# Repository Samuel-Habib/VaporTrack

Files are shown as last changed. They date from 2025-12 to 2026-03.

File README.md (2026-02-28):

# VaporTrack: Autonomous Gas-Detection Rover






VaporTrack is an autonomous robotic rover powered by an **STM32F446RE (ARM Cortex-M4F @ 180 MHz)** running **FreeRTOS**. The rover characterizes spatial volatile organic compound (VOC) gas distributions in indoor environments, computes 2D spatial gradients ($\nabla G = [\partial G/\partial x, \partial G/\partial y]$) via weighted planar least-squares regression, and tracks plume sources while executing reactive obstacle avoidance using a 3-sensor ultrasonic array.

---

## 1. System Architecture

```text
                         ┌─────────────────────────┐
                         │   NUCLEO-F446RE (ARM)   │
                         │   180 MHz Cortex-M4F    │
                         │                         │
                         │   FreeRTOS (CMSIS-V2)   │
                         └────────────┬────────────┘
                                      │
             ┌────────────────────────┼────────────────────────┐
             │                        │                        │
        I2C1 (PB6/PB7)           TIM4 / GPIO             TIM1 PWM (PA8/PA10)
             │                        │                        │
      ┌──────┼──────┐           ┌─────┴─────┐            ┌─────┴─────┐
      │      │      │           │           │            │           │
    BME688 BNO055 OLED      HC-SR04 x3   Heartbeat     L298N H-Bridge
    (Gas)  (IMU)  (Diag)   (PC0 - PC5)     (PA5)             │
                                                       ┌─────┴─────┐
                                                       │           │
                                                   Left 4WD    Right 4WD
```

---

## 2. Hardware Specification

| Subsystem | Component | Bus / Interface | Operational Parameters | Role in System |
| :--- | :--- | :--- | :--- | :--- |
| **MCU** | STM32F446RET6 (Nucleo-64) | On-chip | 180 MHz, 512 KB Flash, 128 KB SRAM, FPU | Main controller, RTOS scheduler, spatial math |
| **RTOS** | FreeRTOS Kernel v10.3.1 | Software | CMSIS-RTOS v2 API, preemptive scheduling | Task timing, thread synchronization, IPC |
| **Gas / Environment** | Bosch BME688 | I2C1 (`0x77`, 100 kHz) | Forced mode, 320°C heater (150 ms dwell) | MOX gas resistance ($R_{gas}$), T, P, RH |
| **IMU / Heading** | Bosch BNO055 | I2C1 (`0x28`, 100 kHz) | NDOF fusion mode, internal sensor fusion | Absolute Euler yaw ($\theta$), dead-reckoning |
| **Diagnostics Display**| SSD1306 0.96" OLED | I2C1 (`0x3C`, 100 kHz) | 128x64 monochrome framebuffer | Real-time telemetry, state, gradient vector |
| **Distance Ranging** | 3x HC-SR04 Ultrasonic | GPIO + TIM4 (1 MHz) | Sequential 10 µs trigger, 1 µs timing resolution | Front, Left, and Right obstacle distance |
| **Motor Driver** | L298N Dual H-Bridge | TIM1 PWM + GPIO | 20 kHz PWM (ARR=8999), 2A max per channel | 4WD differential steering control |
| **Chassis & Motors** | YIKESHU 4WD Chassis | Mechanical | 4x DC gearmotors (1:48 gear ratio) | Differential mobility platform |
| **Power Regulation** | DFRobot DFR0831 Buck | DC-DC Step-Down | 7.4V input $\rightarrow$ 5.0V regulated (3A max) | Clean 5V logic & ultrasonic sensor supply |
| **Battery Source** | 2x 18650 Li-ion Cells | Series Pack (2S) | 7.4V nominal (8.4V peak), 2600 mAh | Primary rover energy source |

### Schematic
Schematic

### PCB Layout (Top)
PCB Layout

---

## 3. Electrical & Power Architecture

```text
   2S 18650 Li-ion Battery
      (7.4V - 8.4V)
           │
           ├───[ Main Switch ]───┬───────────────────────────────► L298N VMS (Motor Power)
           │                     │
           │                     ▼
           │           DFRobot Buck Converter (DFR0831)
           │                 (7.4V -> 5.0V Regulated)
           │                     │
           │                     ├───► HC-SR04 Ultrasonic Array (VCC = 5.0V)
           │                     │
           │                     ▼
           │           Nucleo-64 5V / E5V Rail
           │                     │
           │                     ▼
           │           On-Board LDO (5.0V -> 3.3V)
           │                     │
           │                     ├───► STM32F446RE MCU Core & Peripherals
           │                     ├───► Bosch BME688 Gas Sensor (VDD = 3.3V)
           │                     ├───► Bosch BNO055 9-DOF IMU (VDD = 3.3V)
           │                     └───► SSD1306 128x64 OLED Display (VDD = 3.3V)
           │
           └─────────────────────────────────────────────────────► Common Ground Bus (GND)
```

> [!NOTE]
> **Ground Isolation & Noise Mitigation:**
> The motor return current path through the L298N is tied to the central battery ground tab to prevent high-current switching noise from inducing ground bounce on the 3.3V analog and I2C lines. Echo pins PC1, PC3, and PC5 on the STM32F446RE are true **5V-tolerant (FT)** inputs, allowing direct interface with 5V HC-SR04 echo signals without resistive voltage dividers.

---

## 4. Hardware Pinout Map

| Signal Name | STM32 Pin | Function / Alternate Function | Electrical Characteristics | Notes |
| :--- | :--- | :--- | :--- | :--- |
| `I2C1_SCL` | **PB6** | `AF4` (I2C1) | Open-Drain, 4.7 kΩ pull-up | Shared I2C bus clock (BME688, BNO055, SSD1306) |
| `I2C1_SDA` | **PB7** | `AF4` (I2C1) | Open-Drain, 4.7 kΩ pull-up | Shared I2C bus data line |
| `ENA` (Left PWM) | **PA8** | `AF1` (`TIM1_CH1`) | Push-Pull, 20 kHz PWM | Left motor bank duty cycle (ARR=8999) |
| `ENB` (Right PWM)| **PA10**| `AF1` (`TIM1_CH3`) | Push-Pull, 20 kHz PWM | Right motor bank duty cycle (ARR=8999) |
| `IN1` | **PB10** | GPIO Output | Push-Pull, Low Speed | Left motor forward control |
| `IN2` | **PB4** | GPIO Output | Push-Pull, Low Speed | Left motor reverse control |
| `IN3` | **PB5** | GPIO Output | Push-Pull, Low Speed | Right motor forward control |
| `IN4` | **PB3** | GPIO Output | Push-Pull, Low Speed | Right motor reverse control |
| `USS_FRONT_TRIG` | **PC0** | GPIO Output | Push-Pull, High Speed | Front ultrasonic 10 µs trigger pulse |
| `USS_FRONT_ECHO` | **PC1** | GPIO Input (`FT` 5V-tolerant) | Floating / Internal Pull-down | Front echo pulse width measurement |
| `USS_LEFT_TRIG` | **PC2** | GPIO Output | Push-Pull, High Speed | Left ultrasonic 10 µs trigger pulse |
| `USS_LEFT_ECHO` | **PC3** | GPIO Input (`FT` 5V-tolerant) | Floating / Internal Pull-down | Left echo pulse width measurement |
| `USS_RIGHT_TRIG`| **PC4** | GPIO Output | Push-Pull, High Speed | Right ultrasonic 10 µs trigger pulse |
| `USS_RIGHT_ECHO`| **PC5** | GPIO Input (`FT` 5V-tolerant) | Floating / Internal Pull-down | Right echo pulse width measurement |
| `STATUS_LED` | **PA5** | `AF1` (`TIM2_CH1`) | Push-Pull PWM | Activity heartbeat LED (duty $\propto$ motor drive) |

---

## 5. Software Architecture & FreeRTOS Tasks

The application runs 6 prioritized, decoupled FreeRTOS tasks. Inter-task communication follows a **producer-consumer snapshot model**: sensors update a shared state struct protected by a FreeRTOS mutex (`g_sensor_mutex`), and consumer tasks copy local snapshots to eliminate torn reads without holding the bus.

In addition, access to the shared physical I2C1 bus (`hi2c1`) between `SensorTask` (reading BME688 and BNO055) and `DisplayTask` (flushing 1024-byte framebuffer to SSD1306) is serialized using a dedicated FreeRTOS mutex (`g_i2c_mutex`). To prevent bus starvation during BME688 gas sensor heating, the driver splits forced-mode triggering and data readout: `SensorTask` initiates the measurement, yields CPU execution via `osDelay(160)` while the heater stabilizes, and acquires `g_i2c_mutex` again only when measurement registers are ready to fetch.

```text
                   SensorTask       UltrasonicTask
                  (BME688/BNO055)     (HC-SR04 x3)
                        │                  │
                        ▼                  ▼
                ┌─────────────────────────────────┐
                │    Thread-Safe Sensor Snapshot  │  (sensors.c: g_sensors)
                └────────────────┬────────────────┘
                                 │
                     ┌───────────┴───────────┐
                     ▼                       ▼
                MappingTask           NavigationTask (State Machine)
             (2D Least-Squares)              │
                     │                       ▼
                     └──────────────►   MotorTask (L298N PWM/GPIO)
                                             │
                                             ▼
                                        DisplayTask (SSD1306 OLED)
```

### Task Scheduling Table

| Task Name | Period | Priority | Stack Size | Role & Responsibilities |
| :--- | :--- | :--- | :--- | :--- |
| **`MotorTask`** | 50 ms | `osPriorityHigh` (40) | 256 words (1 KB) | Translates navigation velocity commands to TIM1 PWM compare values and GPIO directions. |
| **`SensorTask`** | 250 ms | `osPriorityAboveNormal` (32) | 512 words (2 KB) | Triggers BME688 forced-mode gas read and polls BNO055 Euler heading in NDOF mode. |
| **`NavTask`** | 150 ms | `osPriorityAboveNormal` (32) | 512 words (2 KB) | Dead-reckoning position integration, state machine updates, and obstacle avoidance overrides. |
| **`USSTask`** | 100 ms | `osPriorityNormal` (24) | 256 words (1 KB) | Sequentially fires HC-SR04 triggers using TIM4 1 MHz counter with 1 ms inter-ping decay gaps. |
| **`MapTask`** | 500 ms | `osPriorityNormal` (24) | 512 words (2 KB) | Logs spatial samples and solves 2D planar weighted least-squares system for $\nabla G$. |
| **`DispTask`** | 500 ms | `osPriorityBelowNormal` (16) | 512 words (2 KB) | Formats telemetry strings and flushes 1024-byte framebuffer to SSD1306 OLED over I2C. |

---

## 6. Gas Mapping & Gradient Localization Theory

Standard plume-tracking approaches rely on instantaneous concentration thresholds (`if gas > threshold -> move forward`). In indoor environments, turbulent eddies and diffusion create local pockets of high concentration, causing naive rovers to stall or oscillate. VaporTrack uses a **two-pass planar spatial gradient estimation**:

### 1. Spatial Sample Acquisition
As the rover maneuvers, it logs discrete coordinate tuples:
$$S_i = (x_i, y_i, \theta_i, G_i)$$
Where $(x_i, y_i)$ is dead-reckoned position derived from heading $\theta_i$ and differential wheel displacement.

Because the BME688 metal-oxide semiconductor (MOX) sensor's raw resistance $R_{\text{gas}}$ drops when reducing VOC vapors interact with its heated sensing layer, the rover converts raw resistance into relative conductance $G_i$ ($\mu\text{S}$):
$$G_i = \frac{10^6}{R_{\text{gas}, i}}$$
This inversion guarantees that $G_i$ increases proportionally with gas plume concentration, allowing standard gradient ascent to naturally steer toward the gas source without sign inversion.

### 2. Weighted Planar Least-Squares Regression
In the localization phase, the rover models the local gas distribution in a neighborhood of radius R as a first-order planar surface centered at (x, y).

Setting up the normal equations:
```text
[ Sum(dx^2)    Sum(dx*dy) ] [ b ] = [ Sum(dx*G) ]
[ Sum(dx*dy)   Sum(dy^2)  ] [ c ] = [ Sum(dy*G) ]
```

Solving via Cramer's rule:
```text
D = Sum(dx^2)*Sum(dy^2) - Sum(dx*dy)^2

b = (Sum(dx*G)*Sum(dy^2) - Sum(dy*G)*Sum(dx*dy)) / D
c = (Sum(dx^2)*Sum(dy*G) - Sum(dx*dy)*Sum(dx*G)) / D
```

### 3. Gradient Ascent Steering
The estimated gradient vector gives the direction of steepest concentration change:
```text
Grad(G) = [b, c]
target_heading = atan2(c, b)
```

The rover computes heading error $e_\theta = \theta_{\text{target}} - \theta_{\text{current}}$ and applies differential steering proportional to $e_\theta$. When $\|\nabla G\|$ drops below the planar detection threshold and $G$ exceeds the plume peak threshold, the rover transitions to `NAV_STATE_SOURCE_FOUND`.

---

## 7. Navigation State Machine & Safety Overrides

```text
    ┌──────────────┐
    │  STATE_BOOT  │
    └──────┬───────┘
           │ Hardware peripherals ready
           ▼
    ┌──────────────┐
    │ INIT_SENSORS │
    └──────┬───────┘
           │ I2C devices acknowledged
           ▼
    ┌──────────────┐
    │ CALIBRATION  │◄────────┐ BNO055 NDOF cal dance
    └──────┬───────┘         │ (sys >= 1, gyro+mag >= 2)
           │ Calibration OK  │
           ▼                 │
    ┌──────────────┐         │
    │   MAPPING    ├─────────┘
    └──────┬───────┘
           │ Waypoint quota reached (>= 64 samples)
           ▼
    ┌──────────────┐
    │ LOCALIZATION │
    └──────┬───────┘
           │ Valid gradient computed (|grad| > threshold)
           ▼
    ┌──────────────┐
    │   TRACKING   ├───────────────────────────────┐
    └──────┬───────┘                               │
           │ Gas peak reached & grad flat          │
           ▼                                       ▼
    ┌──────────────┐                      ┌─────────────────┐
    │ SOURCE_FOUND │                      │ OBSTACLE_AVOID  │
    └──────────────┘                      └─────────────────┘
                                           ▲ (Preempts any state
                                           │  if d_front < 20 cm)
```

* **Obstacle Preemption:** If `dist_front_cm < 20.0 cm` or either side sensor detects an obstacle `< 15.0 cm`, the rover immediately halts forward movement and transitions into `NAV_STATE_OBSTACLE_AVOID`.
* **Escape Maneuver:** The rover pivots away from the closer side until clearance exceeds `40.0 cm`, then restores the previous state to resume gradient navigation.

---

## 8. Repository Layout

```text
VaporTrack/
├── Core/
│   ├── Inc/
│   │   ├── bme688.h           # Bosch BME688 MOX gas & environmental driver header
│   │   ├── bno055.h           # Bosch BNO055 9-DOF IMU & Euler orientation header
│   │   ├── hcsr04.h           # 3-channel HC-SR04 ultrasonic driver header
│   │   ├── ssd1306.h          # 128x64 OLED framebuffer driver & font header
│   │   ├── motor.h            # L298N differential drive & PWM interface header
│   │   ├── sensors.h          # Mutex-protected thread-safe sensor snapshot header
│   │   ├── mapping.h          # 2D spatial sample grid & least-squares gradient header
│   │   ├── navigation.h       # Autonomous finite state machine & obstacle avoidance header
│   │   ├── main.h             # Pin assignments, peripheral exports, and clock macros
│   │   └── FreeRTOSConfig.h   # FreeRTOS kernel configuration (32 KB heap, FPU enabled)
│   └── Src/
│       ├── bme688.c           # BME688 register access & datasheet compensation formulas
│       ├── bno055.c           # BNO055 NDOF mode setup & Euler heading acquisition
│       ├── hcsr04.c           # TIM4 microsecond pulse width timing & distance calculation
│       ├── ssd1306.c          # Framebuffer manipulation & 6x8 ASCII font renderer
│       ├── motor.c            # TIM1 PWM duty update & GPIO direction control
│       ├── sensors.c          # Global sensor snapshot & FreeRTOS mutex synchronization
│       ├── mapping.c          # Planar regression solver using Cramer's rule
│       ├── navigation.c       # Navigation state machine, steering laws & obstacle overrides
│       ├── main.c             # System clock setup, peripheral init & FreeRTOS task threads
│       └── stm32f4xx_hal_msp.c# Low-level MSP peripheral clock and GPIO initialization
├── Drivers/                   # STMicroelectronics STM32F4xx HAL & ARM CMSIS sources
├── Middlewares/               # FreeRTOS Kernel v10.3.1 sources and CMSIS-RTOS v2 wrapper
├── cmake/                     # CMake toolchain definitions for arm-none-eabi-gcc
├── vapor_track.ioc            # STM32CubeMX graphical configuration file
├── CMakeLists.txt             # Root CMake build configuration
├── commands.sh                # Portable build and test automation script
├── openocd.cfg                # OpenOCD target configuration for ST-Link V2/V2-1
└── LICENSE                    # MIT License
```

---

## 9. Building and Flashing

### Toolchain Prerequisites
* **CMake** $\ge$ 3.22
* **Ninja** or **Make**
* **GNU Arm Embedded Toolchain** (`arm-none-eabi-gcc` $\ge$ 10.3)
* **stlink-tools** or **OpenOCD**

### Compilation
```bash
# Clone repository
git clone https://github.com/Samuel-Habib/VaporTrack.git
cd VaporTrack

# Configure build directory
cmake -DCMAKE_TOOLCHAIN_FILE=cmake/gcc-arm-none-eabi.cmake -DCMAKE_BUILD_TYPE=Debug -B build

# Build ELF and generate binary
cmake --build build -j$(nproc 2>/dev/null || sysctl -n hw.logicalcpu)
```

### Flashing to STM32 Target
```bash
# Flash using CMake target (via st-flash)
cmake --build build --target flash

# Or flash binary directly with st-flash
st-flash --connect-under-reset --reset write build/vapor_track.bin 0x08000000

# Or using OpenOCD
openocd -f openocd.cfg -c "program build/vapor_track.elf verify reset exit"
```

---

## 10. Bench Calibration & Verification

1. **IMU Heading Calibration:** On power-up, the rover remains stationary for 3 seconds to let the gyroscope calibrate, then executes a slow rotational pivot. The OLED displays `CAL S:<sys> G:<gyro> M:<mag>`. Once `mag >= 2` and `gyro == 3`, calibration locks.
2. **Ultrasonic Ranging Verification:** Each channel can be probed on PC1, PC3, and PC5 with a logic analyzer. A 10 µs pulse on trigger generates an echo high pulse between 116 µs (2 cm) and 23.2 ms (400 cm).
3. **VOC Sensor Response Verification:** Exposing the BME688 to an isopropyl alcohol vapor source causes the MOX sensor resistance $R_{gas}$ to drop sharply from ~150 kΩ to < 10 kΩ. The OLED reflects real-time $R_{gas}$ drops and computes gradient vector arrows on the display.
4. **Motor Differential Trim:** If the chassis drifts slightly under equal PWM duty cycles due to motor gearbox variance, adjust `NAV_SPEED_CRUISE` offsets in `Core/Inc/navigation.h`.

---

## 11. License

This project is licensed under the MIT License - see the [LICENSE](LICENSE) file for details.

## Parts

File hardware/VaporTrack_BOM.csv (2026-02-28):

Item | Designator | Qty | Value | Package | Description | Suggested MPN | DigiKey Example
1 | C1, C2 | 2 | 10uF | 0805 | Capacitor 10uF 16V X7R 0805 | CL21A106KOQNNNE
2 | C3, C5, C6, C7, C8, C9 | 6 | 100nF | 0805 | Capacitor 0.1uF 50V X7R 0805 | CL21B104KBCNNNC
3 | C4 | 1 | 2.2uF | 0805 | Capacitor 2.2uF 16V X7R 0805 (VCAP) | CL21B225KOFNNNE
4 | R1 | 1 | 10k | 0805 | Resistor 10k 5% 0805 (BOOT0) | RC0805JR-0710KL
5 | R2, R3 | 2 | 4.7k | 0805 | Resistor 4.7k 5% 0805 (I2C Pullup) | RC0805JR-074K7L
6 | R4 | 1 | 330 | 0805 | Resistor 330 ohm 5% 0805 (LED) | RC0805JR-07330RL
7 | D1 | 1 | LED | 0805 | LED Green/Red 0805
8 | U1 | 1 | AMS1117-3.3 | SOT-223 | LDO Voltage Regulator 3.3V 1A
9 | U2 | 1 | STM32F446RET6 | LQFP-64 | MCU ARM Cortex-M4 180MHz 512KB Flash
10 | J1 | 1 | 2-pin Header | 2.54mm TH | Pin Header 1x02 2.54mm
11 | J2 | 1 | 5-pin Header | 2.54mm TH | SWD Debug Header 1x05 2.54mm
12 | J3, J4, J5, J6, J7, J8 | 6 | 4-pin Header | 2.54mm TH | Sensor Headers 1x04 2.54mm
13 | J9 | 1 | 7-pin Header | 2.54mm TH | Motor Driver Header 1x07 2.54mm

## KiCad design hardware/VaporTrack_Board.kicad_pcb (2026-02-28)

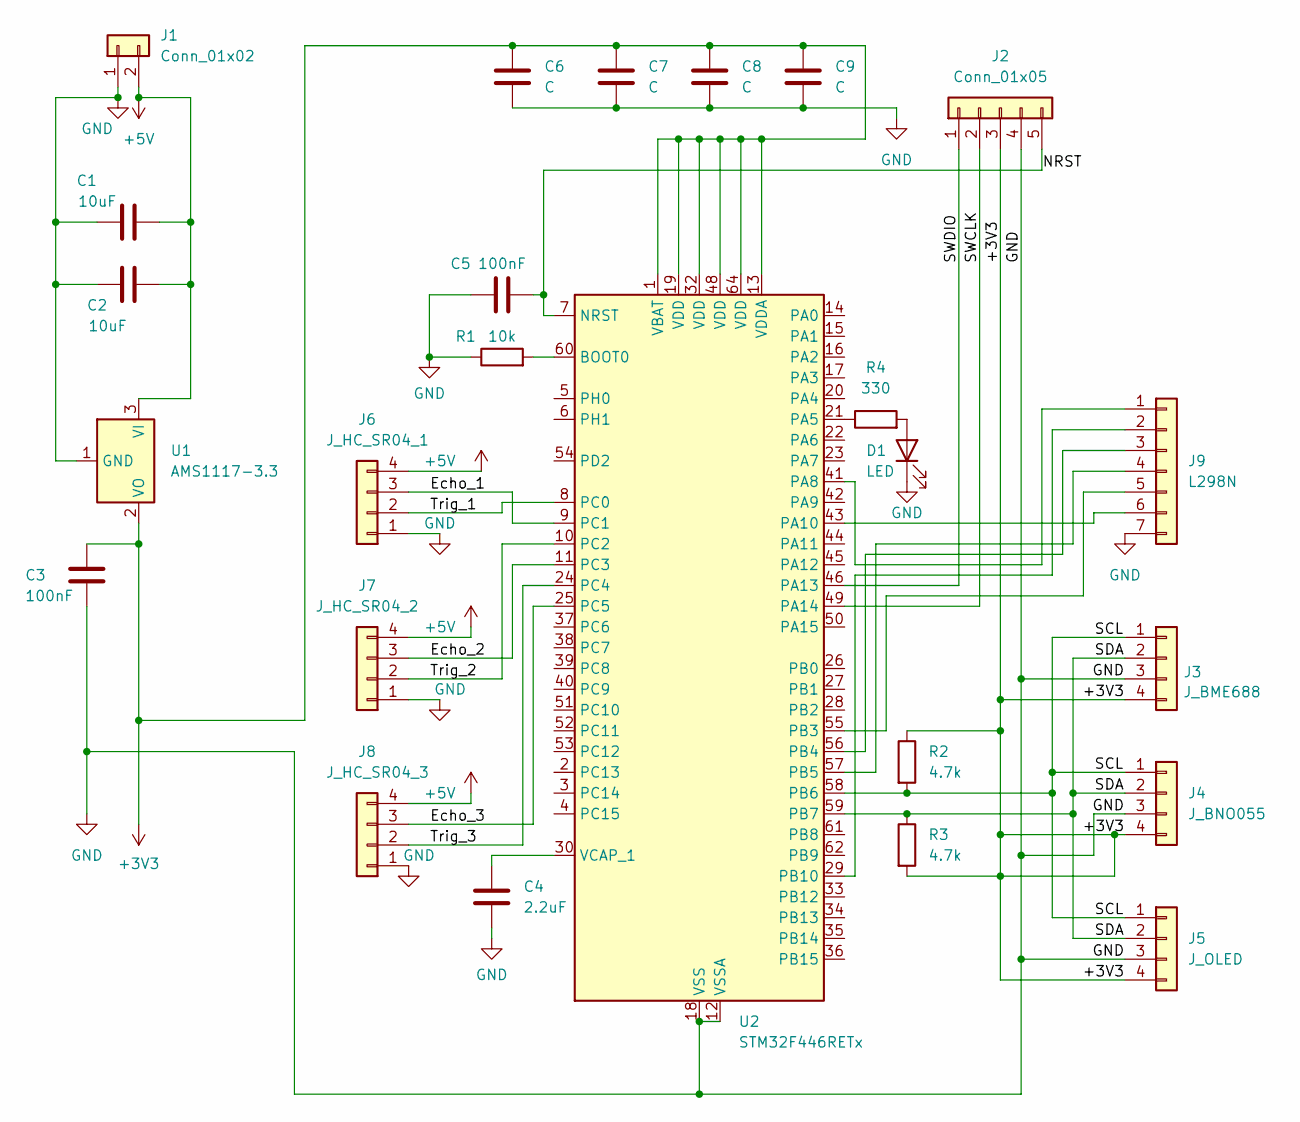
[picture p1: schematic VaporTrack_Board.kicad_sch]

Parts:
C1, C2: 10uF; C_0805_2012Metric
C3, C5: 100nF; C_0805_2012Metric
C4: 2.2uF; C_0805_2012Metric
C6, C7, C8, C9: C; C_0805_2012Metric
D1: LED; LED_0805_2012Metric
J1: Conn_01x02; PinHeader_1x02_P2.54mm_Vertical
J2: Conn_01x05; PinHeader_1x05_P2.54mm_Vertical
J3: J_BME688; PinHeader_1x04_P2.54mm_Vertical
J4: J_BNO055; PinHeader_1x04_P2.54mm_Vertical
J5: J_OLED; PinHeader_1x04_P2.54mm_Vertical
J6: J_HC_SR04_1; PinHeader_1x04_P2.54mm_Vertical
J7: J_HC_SR04_2; PinHeader_1x04_P2.54mm_Vertical
J8: J_HC_SR04_3; PinHeader_1x04_P2.54mm_Vertical
J9: L298N; PinHeader_1x07_P2.54mm_Vertical
R1: 10k; R_0805_2012Metric
R2, R3: 4.7k; R_0805_2012Metric
R4: 330; R_0805_2012Metric
U1: AMS1117-3.3; SOT-223-3_TabPin2
U2: STM32F446RETx; LQFP-64_10x10mm_P0.5mm

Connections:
+3V3: C3.1, C6.1, C7.2, C8.2, C9.1, J2.3, J3.4, J4.4, J5.4, R2.1, R3.2, U1.2 (VO), U2.1 (VBAT), U2.13 (VDDA), U2.19 (VDD), U2.32 (VDD), U2.48 (VDD), U2.64 (VDD)
+5V: C1.2, C2.2, J1.2, J6.4, J7.4, J8.4, U1.3 (VI)
/Echo_1: J6.3, U2.9 (PC1)
/Echo_2: J7.3, U2.11 (PC3)
/Echo_3: J8.3, U2.25 (PC5)
/NRST: C5.1, J2.5, U2.7 (NRST)
/SCL: J3.1, J4.1, J5.1, R2.2, U2.58 (PB6)
/SDA: J3.2, J4.2, J5.2, R3.1, U2.59 (PB7)
/SWCLK: J2.2, U2.49 (PA14)
/SWDIO: J2.1, U2.46 (PA13)
/Trig_1: J6.2, U2.8 (PC0)
/Trig_2: J7.2, U2.10 (PC2)
/Trig_3: J8.2, U2.24 (PC4)
GND: C1.1, C2.1, C3.2, C4.2, C5.2, C6.2, C7.1, C8.1, C9.2, D1.1 (K), J1.1, J2.4, J3.3, J4.3, J5.3, J6.1, J7.1, J8.1, J9.7, R1.1, U1.1 (GND), U2.12 (VSSA), U2.18 (VSS), U2.31 (VSS), U2.47 (VSS), U2.63 (VSS)
unnamed: D1.2 (A), R4.2
unnamed: J9.1, U2.41 (PA8)
unnamed: J9.2, U2.29 (PB10)
unnamed: J9.3, U2.56 (PB4)
unnamed: J9.4, U2.57 (PB5)
unnamed: J9.5, U2.55 (PB3)
unnamed: J9.6, U2.43 (PA10)
unnamed: R1.2, U2.60 (BOOT0)
unnamed: R4.1, U2.21 (PA5)
unnamed: C4.1, U2.30 (VCAP_1)

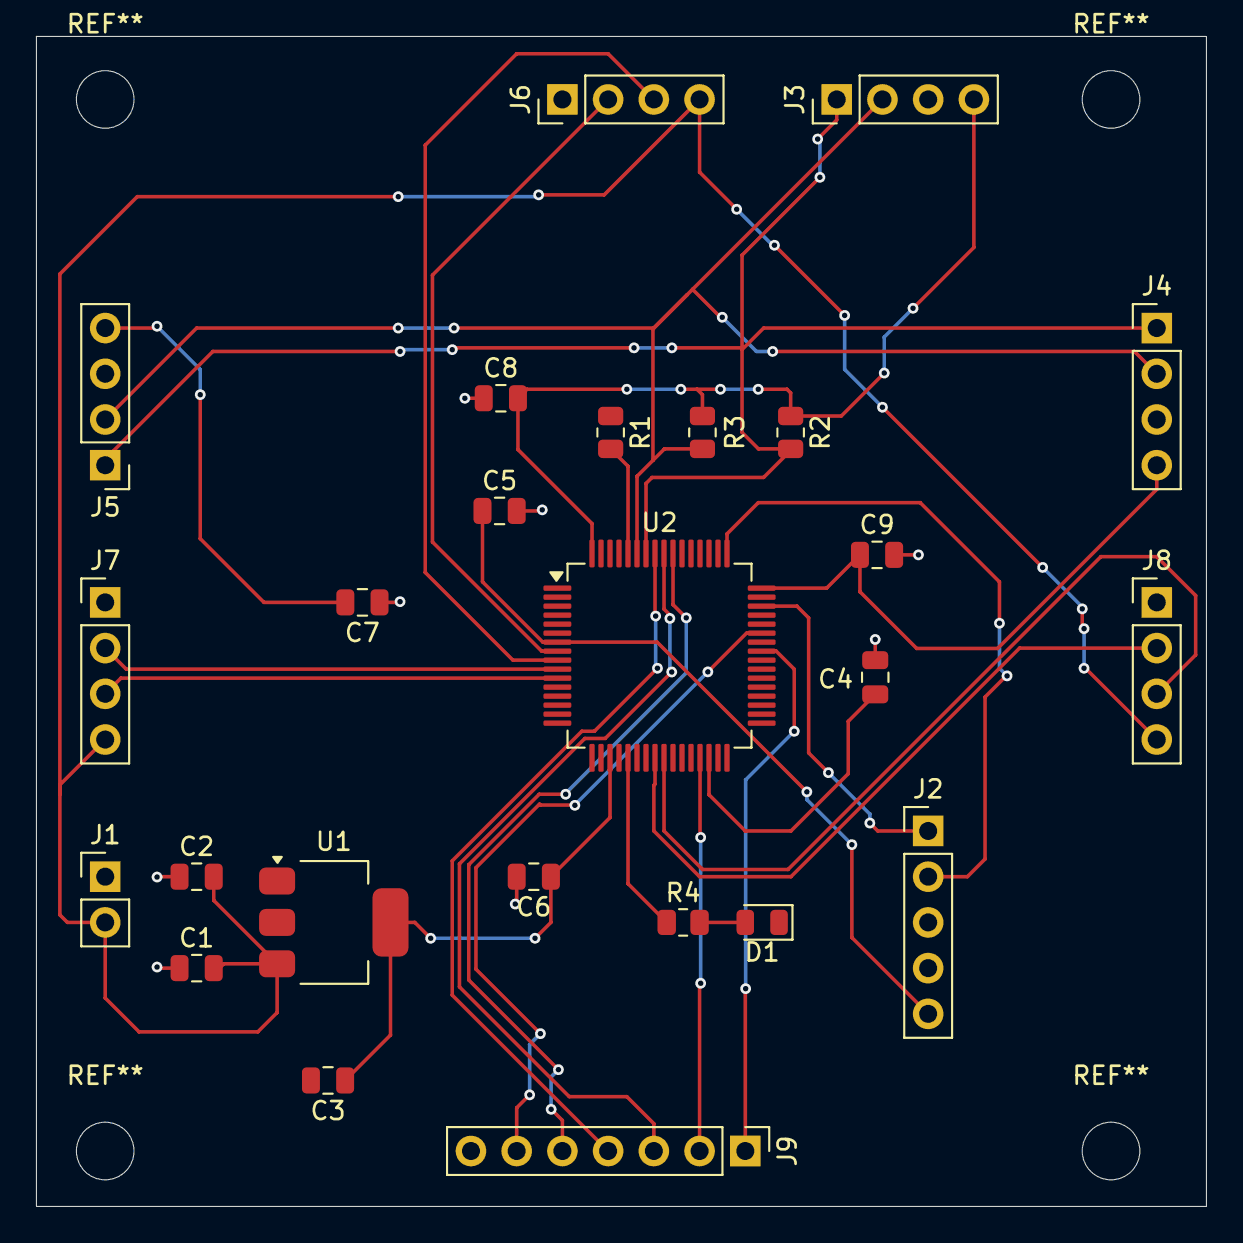
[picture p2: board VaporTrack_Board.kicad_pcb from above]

Board: 2 copper layers, 65.0 x 65.0 mm, 25 parts (0 on the bottom side), 24 nets.

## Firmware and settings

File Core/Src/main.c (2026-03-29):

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
/* Includes ------------------------------------------------------------------*/
#include "main.h"
#include "cmsis_os.h"

/* USER CODE BEGIN Includes */
#include "cmsis_os2.h"
#include "bme688.h"
#include "bno055.h"
#include "hcsr04.h"
#include "ssd1306.h"
#include "motor.h"
#include "sensors.h"
#include "mapping.h"
#include "navigation.h"

#include <stdio.h>
#include <string.h>
#include <math.h>
#include <stdlib.h>
/* USER CODE END Includes */

I2C_HandleTypeDef hi2c1;

TIM_HandleTypeDef htim1;
TIM_HandleTypeDef htim2;
TIM_HandleTypeDef htim4;

/* Definitions for SensorTask */
osThreadId_t SensorTaskHandle;
const osThreadAttr_t SensorTask_attributes = {
  .name = "SensorTask",
  .stack_size = 512 * 4,
  .priority = (osPriority_t) osPriorityAboveNormal,
};
/* Definitions for UltrasonicTask */
osThreadId_t UltrasonicTaskHandle;
const osThreadAttr_t UltrasonicTask_attributes = {
  .name = "USSTask",
  .stack_size = 256 * 4,
  .priority = (osPriority_t) osPriorityNormal,
};
/* Definitions for NavTask */
osThreadId_t NavTaskHandle;
const osThreadAttr_t NavTask_attributes = {
  .name = "NavTask",
  .stack_size = 512 * 4,
  .priority = (osPriority_t) osPriorityAboveNormal,
};
/* Definitions for MotorTask */
osThreadId_t MotorTaskHandle;
const osThreadAttr_t MotorTask_attributes = {
  .name = "MotorTask",
  .stack_size = 256 * 4,
  .priority = (osPriority_t) osPriorityHigh,
};
/* Definitions for MappingTask */
osThreadId_t MappingTaskHandle;
const osThreadAttr_t MappingTask_attributes = {
  .name = "MapTask",
  .stack_size = 512 * 4,
  .priority = (osPriority_t) osPriorityNormal,
};
/* Definitions for DisplayTask */
osThreadId_t DisplayTaskHandle;
const osThreadAttr_t DisplayTask_attributes = {
  .name = "DispTask",
  .stack_size = 512 * 4,
  .priority = (osPriority_t) osPriorityBelowNormal,
};
/* USER CODE BEGIN PV */
static bme688_dev_t   g_bme;
static bno055_dev_t   g_bno;
static hcsr04_dev_t   g_uss;
static ssd1306_dev_t  g_oled;
static motor_dev_t    g_motor;

static gas_map_t      g_map;
static nav_ctx_t      g_nav;

static volatile motor_cmd_t g_motor_cmd;
static SemaphoreHandle_t    g_motor_mutex;
static SemaphoreHandle_t    g_i2c_mutex;

static volatile bool g_bme_ok   = false;
static volatile bool g_bno_ok   = false;
static volatile bool g_oled_ok  = false;
/* USER CODE END PV */

void SystemClock_Config(void);
static void MX_GPIO_Init(void);
static void MX_I2C1_Init(void);
static void MX_TIM1_Init(void);
static void MX_TIM2_Init(void);
static void MX_TIM4_Init(void);
void SensorTask_Entry(void *argument);
void UltrasonicTask_Entry(void *argument);
void NavigationTask_Entry(void *argument);
void MotorTask_Entry(void *argument);
void MappingTask_Entry(void *argument);
void DisplayTask_Entry(void *argument);

/* USER CODE BEGIN PFP */
static inline void i2c_lock(void)
{
  if (g_i2c_mutex != NULL)
    xSemaphoreTake(g_i2c_mutex, portMAX_DELAY);
}

static inline void i2c_unlock(void)
{
  if (g_i2c_mutex != NULL)
    xSemaphoreGive(g_i2c_mutex);
}
/* USER CODE END PFP */

/**
  * @brief  The application entry point.
  * @retval int
  */
int main(void)
{
  /* MCU Configuration--------------------------------------------------------*/

  /* Reset of all peripherals, Initializes the Flash interface and the Systick. */
  HAL_Init();

  /* Configure the system clock */
  SystemClock_Config();

  /* Initialize all configured peripherals */
  MX_GPIO_Init();
  MX_I2C1_Init();
  MX_TIM1_Init();
  MX_TIM2_Init();
  MX_TIM4_Init();
  /* USER CODE BEGIN 2 */

  HAL_TIM_PWM_Start(&htim1, TIM_CHANNEL_1);
  HAL_TIM_PWM_Start(&htim1, TIM_CHANNEL_3);
  HAL_TIM_PWM_Start(&htim2, TIM_CHANNEL_1);

  sensors_init();
  map_init(&g_map);
  nav_init(&g_nav, &g_map);
  motor_init(&g_motor, &htim1);

  g_motor_mutex = xSemaphoreCreateMutex();
  g_i2c_mutex   = xSemaphoreCreateMutex();
  configASSERT(g_motor_mutex != NULL);
  configASSERT(g_i2c_mutex != NULL);

  /* USER CODE END 2 */

  /* Init scheduler */
  osKernelInitialize();

  /* Create the thread(s) */
  SensorTaskHandle = osThreadNew(SensorTask_Entry, NULL, &SensorTask_attributes);
  UltrasonicTaskHandle = osThreadNew(UltrasonicTask_Entry, NULL, &UltrasonicTask_attributes);
  NavTaskHandle = osThreadNew(NavigationTask_Entry, NULL, &NavTask_attributes);
  MotorTaskHandle = osThreadNew(MotorTask_Entry, NULL, &MotorTask_attributes);
  MappingTaskHandle = osThreadNew(MappingTask_Entry, NULL, &MappingTask_attributes);
  DisplayTaskHandle = osThreadNew(DisplayTask_Entry, NULL, &DisplayTask_attributes);

  /* Start scheduler */
  osKernelStart();

  /* We should never get here as control is now taken by the scheduler */
  /* Infinite loop */
  /* USER CODE BEGIN WHILE */
  while (1)
  {
    /* USER CODE END WHILE */

    /* USER CODE BEGIN 3 */
  }
  /* USER CODE END 3 */
}

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
/* USER CODE BEGIN Header_SensorTask_Entry */
/**
  * @brief  Function implementing the SensorTask thread.
  * @param  argument: Not used
  * @retval None
  */
/* USER CODE END Header_SensorTask_Entry */
void SensorTask_Entry(void *argument)
{
  /* USER CODE BEGIN 5 */
  (void)argument;

  i2c_lock();
  if (bme688_init(&g_bme, &hi2c1) == BME688_OK)
    g_bme_ok = true;

  if (bno055_init(&g_bno, &hi2c1) == BNO055_OK)
    g_bno_ok = true;
  i2c_unlock();

  for (;;)
  {
    uint32_t now = HAL_GetTick();

    if (g_bme_ok)
    {
      bme688_data_t env;
      i2c_lock();
      bme688_status_t trig_res = bme688_trigger_forced(&g_bme);
      i2c_unlock();

      if (trig_res == BME688_OK)
      {
        /* Yield to RTOS while sensor heater stabilizes (150ms dwell).
         * I2C bus is released so DisplayTask can flush without contention. */
        osDelay(160);

        i2c_lock();
        bme688_status_t read_res = bme688_read_data(&g_bme, &env);
        i2c_unlock();

        if (read_res == BME688_OK)
        {
          sensors_lock();
          g_sensors.gas_resistance   = env.gas_resistance;
          g_sensors.temperature      = env.temperature;
          g_sensors.humidity         = env.humidity;
          g_sensors.pressure         = env.pressure;
          g_sensors.gas_valid        = env.gas_valid;
          g_sensors.gas_heater_stable = env.heat_stab;
          g_sensors.gas_timestamp_ms  = now;
          sensors_unlock();
        }
      }
    }

    if (g_bno_ok)
    {
      bno055_euler_t euler;
      bno055_cal_status_t cal;
      i2c_lock();
      bno055_status_t euler_res = bno055_read_euler(&g_bno, &euler);
      if (euler_res == BNO055_OK)
      {
        bno055_get_calibration(&g_bno, &cal);
      }
      i2c_unlock();

      if (euler_res == BNO055_OK)
      {
        sensors_lock();
        g_sensors.heading_deg    = euler.heading;
        g_sensors.roll_deg       = euler.roll;
        g_sensors.pitch_deg      = euler.pitch;
        g_sensors.cal_sys        = cal.sys;
        g_sensors.cal_gyro       = cal.gyro;
        g_sensors.cal_accel      = cal.accel;
        g_sensors.cal_mag        = cal.mag;
        g_sensors.imu_calibrated = bno055_is_calibrated(&cal);
        g_sensors.imu_timestamp_ms = now;
        sensors_unlock();
      }
    }

    osDelay(100);
  }
  /* USER CODE END 5 */
}

/* USER CODE BEGIN Header_UltrasonicTask_Entry */
/**
* @brief Function implementing the UltrasonicTask thread.
* @param argument: Not used
* @retval None
*/
/* USER CODE END Header_UltrasonicTask_Entry */
void UltrasonicTask_Entry(void *argument)
{
  /* USER CODE BEGIN UltrasonicTask_Entry */
  (void)argument;

  hcsr04_init(&g_uss, &htim4);

  g_uss.hw[HCSR04_FRONT].trig_port = USS_FRONT_TRIG_Port;
  g_uss.hw[HCSR04_FRONT].trig_pin  = USS_FRONT_TRIG_Pin;
  g_uss.hw[HCSR04_FRONT].echo_port = USS_FRONT_ECHO_Port;
  g_uss.hw[HCSR04_FRONT].echo_pin  = USS_FRONT_ECHO_Pin;

  g_uss.hw[HCSR04_LEFT].trig_port  = USS_LEFT_TRIG_Port;
  g_uss.hw[HCSR04_LEFT].trig_pin   = USS_LEFT_TRIG_Pin;
  g_uss.hw[HCSR04_LEFT].echo_port  = USS_LEFT_ECHO_Port;
  g_uss.hw[HCSR04_LEFT].echo_pin   = USS_LEFT_ECHO_Pin;

  g_uss.hw[HCSR04_RIGHT].trig_port = USS_RIGHT_TRIG_Port;
  g_uss.hw[HCSR04_RIGHT].trig_pin  = USS_RIGHT_TRIG_Pin;
  g_uss.hw[HCSR04_RIGHT].echo_port = USS_RIGHT_ECHO_Port;
  g_uss.hw[HCSR04_RIGHT].echo_pin  = USS_RIGHT_ECHO_Pin;

  for (;;)
  {
    hcsr04_measure_all(&g_uss);

    sensors_lock();
    g_sensors.dist_front_cm = g_uss.distance_cm[HCSR04_FRONT];
    g_sensors.dist_left_cm  = g_uss.distance_cm[HCSR04_LEFT];
    g_sensors.dist_right_cm = g_uss.distance_cm[HCSR04_RIGHT];
    g_sensors.uss_timestamp_ms = HAL_GetTick();
    sensors_unlock();

    osDelay(100);
  }
  /* USER CODE END UltrasonicTask_Entry */
}

/* USER CODE BEGIN Header_NavigationTask_Entry */
/**
* @brief Function implementing the NavTask thread.
* @param argument: Not used
* @retval None
*/
/* USER CODE END Header_NavigationTask_Entry */
void NavigationTask_Entry(void *argument)
{
  /* USER CODE BEGIN NavigationTask_Entry */
  (void)argument;

  osDelay(500);

  for (;;)
  {
    sensor_data_t snap;
    sensors_copy(&snap);

    nav_sensor_input_t input;
    /* Convert MOX gas resistance (ohms) to relative conductance (uS):
     * As VOC concentration increases, MOX resistance drops, so conductance
     * (1/R) increases proportionally with gas plume intensity. */
    if (snap.gas_resistance > 100.0f) {
      input.gas = 1000000.0f / snap.gas_resistance;
    } else {
      input.gas = 0.0f;
    }
    input.temperature   = snap.temperature;
    input.humidity      = snap.humidity;
    input.pressure      = snap.pressure;
    input.gas_valid     = snap.gas_valid;
    input.heading_deg   = snap.heading_deg;
    input.heading_valid = snap.imu_calibrated;
    input.dist_front_cm = snap.dist_front_cm;
    input.dist_left_cm  = snap.dist_left_cm;
    input.dist_right_cm = snap.dist_right_cm;
    input.pos_x         = g_nav.pos_x;
    input.pos_y         = g_nav.pos_y;

    uint32_t now = HAL_GetTick();
    motor_cmd_t cmd = nav_update(&g_nav, &input, now);

    xSemaphoreTake(g_motor_mutex, portMAX_DELAY);
    g_motor_cmd = cmd;
    xSemaphoreGive(g_motor_mutex);

    sensors_lock();
    g_sensors.pos_x = g_nav.pos_x;
    g_sensors.pos_y = g_nav.pos_y;
    sensors_unlock();

    osDelay(150);
  }
  /* USER CODE END NavigationTask_Entry */
}

/* USER CODE BEGIN Header_MotorTask_Entry */
/**
* @brief Function implementing the MotorTask thread.
* @param argument: Not used
* @retval None
*/
/* USER CODE END Header_MotorTask_Entry */
void MotorTask_Entry(void *argument)
{
  /* USER CODE BEGIN MotorTask_Entry */
  (void)argument;

  for (;;)
  {
    motor_cmd_t cmd;
    xSemaphoreTake(g_motor_mutex, portMAX_DELAY);
    cmd = g_motor_cmd;
    xSemaphoreGive(g_motor_mutex);

    motor_set(&g_motor, cmd.left, cmd.right);

    uint16_t activity = (uint16_t)(abs(cmd.left) + abs(cmd.right)) / 2;
    if (activity < 500) activity = 500;
    __HAL_TIM_SET_COMPARE(&htim2, TIM_CHANNEL_1, activity);

    osDelay(50);
  }
  /* USER CODE END MotorTask_Entry */
}

/* USER CODE BEGIN Header_MappingTask_Entry */
/**
* @brief Function implementing the MappingTask thread.
* @param argument: Not used
* @retval None
*/
/* USER CODE END Header_MappingTask_Entry */
void MappingTask_Entry(void *argument)
{
  /* USER CODE BEGIN MappingTask_Entry */
  (void)argument;

  for (;;)
  {
    sensor_data_t snap;
    sensors_copy(&snap);

    if (g_map.count > 3)
    {
      g_map.gradient = map_estimate_gradient(&g_map, snap.pos_x, snap.pos_y, 1.5f);
    }

    osDelay(500);
  }
  /* USER CODE END MappingTask_Entry */
}

/* USER CODE BEGIN Header_DisplayTask_Entry */
/**
* @brief Function implementing the DisplayTask thread.
* @param argument: Not used
* @retval None
*/
/* USER CODE END Header_DisplayTask_Entry */
void DisplayTask_Entry(void *argument)
{
  /* USER CODE BEGIN DisplayTask_Entry */
  (void)argument;

  i2c_lock();
  if (ssd1306_init(&g_oled, &hi2c1) == SSD1306_OK)
    g_oled_ok = true;
  i2c_unlock();

  char line[22];

  for (;;)
  {
    if (!g_oled_ok)
    {
      osDelay(2000);
      continue;
    }

    sensor_data_t snap;
    sensors_copy(&snap);

    ssd1306_clear(&g_oled);

    snprintf(line, sizeof(line), "%-10s %3d%%",
             nav_state_name(g_nav.state),
             (int)(snap.cal_sys * 33));
    ssd1306_puts(&g_oled, 0, 0, line);

    snprintf(line, sizeof(line), "GAS:%-6d %4.1fC",
             (int)snap.gas_resistance, (double)snap.temperature);
    ssd1306_puts(&g_oled, 0, 8, line);

    snprintf(line, sizeof(line), "H:%4.1f%% P:%5.0f",
             (double)snap.humidity, (double)(snap.pressure / 100.0f));
    ssd1306_puts(&g_oled, 0, 16, line);

    snprintf(line, sizeof(line), "F:%3d L:%3d R:%3d",
             (int)snap.dist_front_cm,
             (int)snap.dist_left_cm,
             (int)snap.dist_right_cm);
    ssd1306_puts(&g_oled, 0, 24, line);

    snprintf(line, sizeof(line), "X:%5.2f Y:%5.2f",
             (double)snap.pos_x, (double)snap.pos_y);
    ssd1306_puts(&g_oled, 0, 32, line);

    snprintf(line, sizeof(line), "HDG:%3d", (int)snap.heading_deg);
    ssd1306_puts(&g_oled, 0, 40, line);

    if (g_map.gradient.valid)
    {
      snprintf(line, sizeof(line), "dG:%+.0f @%3d",
               (double)g_map.gradient.magnitude,
               (int)g_map.gradient.direction_deg);
      ssd1306_puts(&g_oled, 0, 48, line);
    }

    snprintf(line, sizeof(line), "MAP:%d/%d",
             g_map.count, MAP_MAX_SAMPLES);
    ssd1306_puts(&g_oled, 0, 56, line);

    i2c_lock();
    ssd1306_flush(&g_oled);
    i2c_unlock();

    osDelay(500);
  }
  /* USER CODE END DisplayTask_Entry */
}

/**
  * @brief  Period elapsed callback in non blocking mode
  * @note   This function is called  when TIM6 interrupt took place, inside
  * HAL_TIM_IRQHandler(). It makes a direct call to HAL_IncTick() to increment
  * a global variable "uwTick" used as application time base.
  * @param  htim : TIM handle
  * @retval None
  */
void HAL_TIM_PeriodElapsedCallback(TIM_HandleTypeDef *htim)
{
  if (htim->Instance == TIM6) {
    HAL_IncTick();
  }
}

/**
  * @brief  This function is executed in case of error occurrence.
  * @retval None
  */
void Error_Handler(void)
{
  /* USER CODE BEGIN Error_Handler_Debug */
  /* User can add his own implementation to report the HAL error return state */
  __disable_irq();
  while (1)
  {
  }
  /* USER CODE END Error_Handler_Debug */
}

#ifdef  USE_FULL_ASSERT
/**
  * @brief  Reports the name of the source file and the source line number
  *         where the assert_param error has occurred.
  * @param  file: pointer to the source file name
  * @param  line: assert_param error line source number
  * @retval None
  */
void assert_failed(uint8_t *file, uint32_t line)
{
  /* USER CODE BEGIN 6 */
  /* User can add his own implementation to report the file name and line
     number, ex: printf("Wrong parameters value: file %s on line %d\r\n", file, line) */
  (void)file;
  (void)line;
  /* USER CODE END 6 */
}
#endif /* USE_FULL_ASSERT */

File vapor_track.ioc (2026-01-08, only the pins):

Mcu.UserName=STM32F446RETx
PA10.GPIO_Label=ENB
PA10.Signal=S_TIM1_CH3
PA13.Signal=SYS_JTMS-SWDIO
PA14.Signal=SYS_JTCK-SWCLK
PA5.GPIO_Label=LED
PA5.Signal=S_TIM2_CH1_ETR
PA8.GPIO_Label=ENA
PA8.Signal=S_TIM1_CH1
PB10.GPIO_Label=IN1
PB10.Signal=GPIO_Output
PB3.GPIO_Label=IN4
PB3.Signal=GPIO_Output
PB4.GPIO_Label=IN2
PB4.Signal=GPIO_Output
PB5.GPIO_Label=IN3
PB5.Signal=GPIO_Output
PB6.Signal=I2C1_SCL
PB7.Signal=I2C1_SDA
PC0.GPIO_Label=USS_FRONT_TRIG
PC0.Signal=GPIO_Output
PC1.GPIO_Label=USS_FRONT_ECHO
PC1.Signal=GPIO_Input
PC2.GPIO_Label=USS_LEFT_TRIG
PC2.Signal=GPIO_Output
PC3.GPIO_Label=USS_LEFT_ECHO
PC3.Signal=GPIO_Input
PC4.GPIO_Label=USS_RIGHT_TRIG
PC4.Signal=GPIO_Output
PC5.GPIO_Label=USS_RIGHT_ECHO
PC5.Signal=GPIO_Input

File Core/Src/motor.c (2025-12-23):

/*
 * motor.c - L298N differential drive control
 *
 * Left side:  IN1 (PB10) + IN2 (PB4), ENA on TIM1_CH1
 * Right side: IN3 (PB5)  + IN4 (PB3), ENB on TIM1_CH3
 *
 * Positive speed = forward, negative = reverse.
 */

#include "motor.h"
#include "main.h"

static inline int16_t clamp(int16_t val, int16_t lo, int16_t hi)
{
    if (val < lo) return lo;
    if (val > hi) return hi;
    return val;
}

static inline uint16_t abs16(int16_t v)
{
    return (v < 0) ? (uint16_t)(-v) : (uint16_t)v;
}

void motor_init(motor_dev_t *dev, TIM_HandleTypeDef *htim)
{
    dev->htim = htim;
    motor_stop(dev);
}

void motor_set(motor_dev_t *dev, int16_t left, int16_t right)
{
    left  = clamp(left,  -MOTOR_PWM_MAX, MOTOR_PWM_MAX);
    right = clamp(right, -MOTOR_PWM_MAX, MOTOR_PWM_MAX);

    /* left side direction */
    if (left >= 0) {
        HAL_GPIO_WritePin(IN1_GPIO_Port, IN1_Pin, GPIO_PIN_SET);
        HAL_GPIO_WritePin(IN2_GPIO_Port, IN2_Pin, GPIO_PIN_RESET);
    } else {
        HAL_GPIO_WritePin(IN1_GPIO_Port, IN1_Pin, GPIO_PIN_RESET);
        HAL_GPIO_WritePin(IN2_GPIO_Port, IN2_Pin, GPIO_PIN_SET);
    }

    /* right side direction */
    if (right >= 0) {
        HAL_GPIO_WritePin(IN3_GPIO_Port, IN3_Pin, GPIO_PIN_SET);
        HAL_GPIO_WritePin(IN4_GPIO_Port, IN4_Pin, GPIO_PIN_RESET);
    } else {
        HAL_GPIO_WritePin(IN3_GPIO_Port, IN3_Pin, GPIO_PIN_RESET);
        HAL_GPIO_WritePin(IN4_GPIO_Port, IN4_Pin, GPIO_PIN_SET);
    }

    /* set PWM duty */
    __HAL_TIM_SET_COMPARE(dev->htim, TIM_CHANNEL_1, abs16(left));
    __HAL_TIM_SET_COMPARE(dev->htim, TIM_CHANNEL_3, abs16(right));
}

void motor_stop(motor_dev_t *dev)
{
    /* coast: set PWM to 0 and release direction pins */
    __HAL_TIM_SET_COMPARE(dev->htim, TIM_CHANNEL_1, 0);
    __HAL_TIM_SET_COMPARE(dev->htim, TIM_CHANNEL_3, 0);

    HAL_GPIO_WritePin(IN1_GPIO_Port, IN1_Pin, GPIO_PIN_RESET);
    HAL_GPIO_WritePin(IN2_GPIO_Port, IN2_Pin, GPIO_PIN_RESET);
    HAL_GPIO_WritePin(IN3_GPIO_Port, IN3_Pin, GPIO_PIN_RESET);
    HAL_GPIO_WritePin(IN4_GPIO_Port, IN4_Pin, GPIO_PIN_RESET);
}

void motor_brake(motor_dev_t *dev)
{
    /* brake: both direction pins high on each side, full PWM */
    HAL_GPIO_WritePin(IN1_GPIO_Port, IN1_Pin, GPIO_PIN_SET);
    HAL_GPIO_WritePin(IN2_GPIO_Port, IN2_Pin, GPIO_PIN_SET);
    HAL_GPIO_WritePin(IN3_GPIO_Port, IN3_Pin, GPIO_PIN_SET);
    HAL_GPIO_WritePin(IN4_GPIO_Port, IN4_Pin, GPIO_PIN_SET);

    __HAL_TIM_SET_COMPARE(dev->htim, TIM_CHANNEL_1, MOTOR_PWM_MAX);
    __HAL_TIM_SET_COMPARE(dev->htim, TIM_CHANNEL_3, MOTOR_PWM_MAX);
}

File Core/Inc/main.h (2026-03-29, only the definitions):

#define LED_Pin             GPIO_PIN_5
#define LED_GPIO_Port       GPIOA
#define IN1_Pin             GPIO_PIN_10
#define IN1_GPIO_Port       GPIOB
#define IN2_Pin             GPIO_PIN_4
#define IN2_GPIO_Port       GPIOB
#define IN3_Pin             GPIO_PIN_5
#define IN3_GPIO_Port       GPIOB
#define IN4_Pin             GPIO_PIN_3
#define IN4_GPIO_Port       GPIOB
#define ENA_Pin             GPIO_PIN_8
#define ENA_GPIO_Port       GPIOA
#define ENB_Pin             GPIO_PIN_10
#define ENB_GPIO_Port       GPIOA
#define USS_FRONT_TRIG_Pin  GPIO_PIN_0
#define USS_FRONT_TRIG_Port GPIOC
#define USS_FRONT_ECHO_Pin  GPIO_PIN_1
#define USS_FRONT_ECHO_Port GPIOC
#define USS_LEFT_TRIG_Pin   GPIO_PIN_2
#define USS_LEFT_TRIG_Port  GPIOC
#define USS_LEFT_ECHO_Pin   GPIO_PIN_3
#define USS_LEFT_ECHO_Port  GPIOC
#define USS_RIGHT_TRIG_Pin  GPIO_PIN_4
#define USS_RIGHT_TRIG_Port GPIOC
#define USS_RIGHT_ECHO_Pin  GPIO_PIN_5
#define USS_RIGHT_ECHO_Port GPIOC

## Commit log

2025-12-08 init: initial project setup from STM32CubeMX with FreeRTOS and CMake
2025-12-16 motor: implement L298N dual H-bridge driver with TIM1 PWM
2025-12-23 motor: add speed clamping, direction logic, and active braking
2026-01-08 timer: configure TIM4 prescaler for 1MHz microsecond timebase
2026-01-17 hcsr04: add 3-channel ultrasonic distance ranging driver
2026-02-03 imu: add BNO055 9-DOF driver for NDOF Euler heading acquisition
2026-02-12 display: add SSD1306 128x64 OLED driver with framebuffer and font
2026-02-19 bme688: implement forced-mode gas sensor driver with compensation formulas
2026-02-28 sensors: centralize telemetry state with FreeRTOS mutex synchronization
2026-02-28 Add schematic and PCB layout images to README
2026-02-28 hardware: add KiCad PCB and schematic files to repo
    [VaporTrack_BOM.csv, VaporTrack_Board.kicad_pcb, VaporTrack_Board.kicad_sch]
2026-02-28 hardware: update 3D model paths from KiCad 6 to KiCad 7
    [VaporTrack_Board.kicad_pcb]
2026-02-28 hardware: flatten directory structure for cleaner repository layout
    [VaporTrack_BOM.csv, VaporTrack_Board.kicad_pcb, VaporTrack_Board.kicad_sch]
2026-03-07 mapping: implement dead-reckoned spatial coordinate and gas sample buffer
2026-03-24 nav: add finite state machine with ultrasonic obstacle override
2026-03-29 rtos: integrate 6-task scheduling loop, task priorities, and heartbeat PWM

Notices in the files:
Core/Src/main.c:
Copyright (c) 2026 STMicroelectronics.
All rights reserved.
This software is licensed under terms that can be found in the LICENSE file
